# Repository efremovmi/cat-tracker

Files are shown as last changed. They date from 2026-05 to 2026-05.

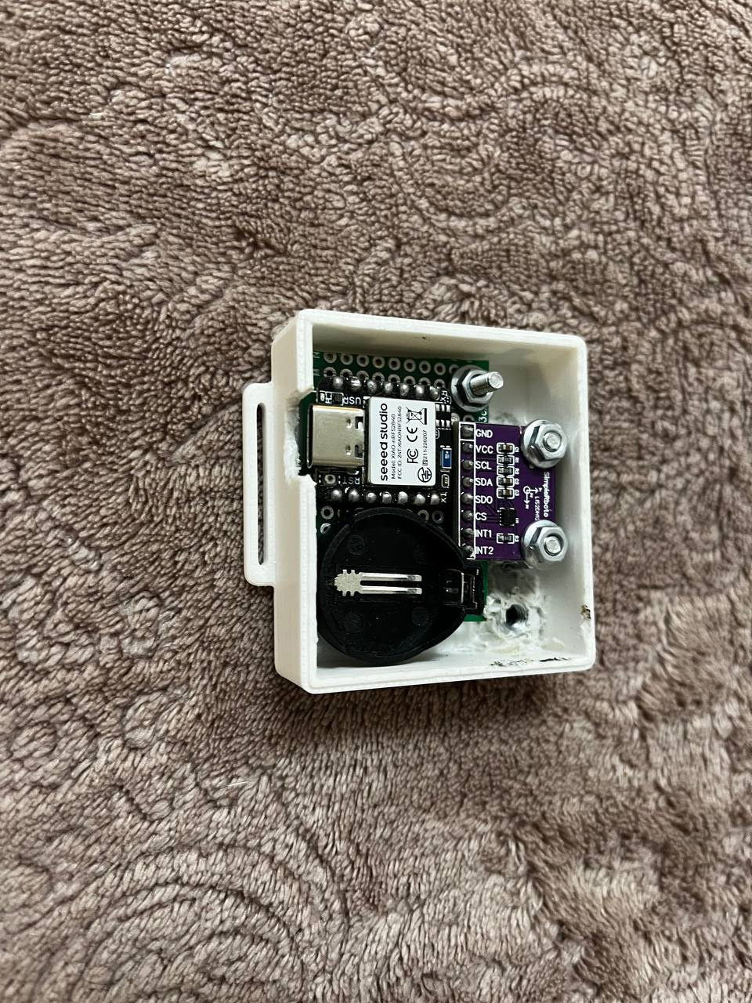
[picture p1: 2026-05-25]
images/6.jpg

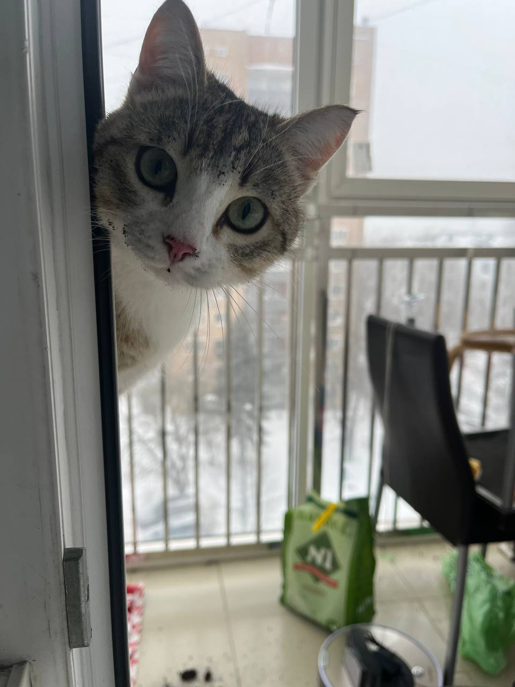
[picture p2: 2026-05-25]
images/1.jpg

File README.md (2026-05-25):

# Cat Activity Tracker (XIAO nRF52840 sence + LIS2DH12)

A cat activity tracker project based on XIAO and the LIS2DH12 accelerometer.
The firmware tracks activity, steps (estimated), distance, jumps, stores hourly statistics, and sends data over BLE.

The project is inspired by nihilism and follows several goals:
- Minimalism
- High autonomy
- Cat safety
- Avoiding an excessive number of unnecessary features
- Enjoying the process
- Helping study the cat's health

## What the system does

- Runs in two sensor modes:
  - `WAKE`: low power, waiting for motion
  - `ACTIVE`: reading samples and motion analysis
- Builds movement segments and filters noise.
- Estimates:
  - `steps` (via stride length)
  - `meters` (via segment duration and speed estimation)
  - `activePoints`
  - `jumps`
- Saves state to Flash (`LittleFS`) and keeps hourly buckets.
- Returns stats via BLE command `GET_STATS`.

## Runtime logic (process)

1. **Device startup**
- Initializes LED, battery ADC, filesystem, accelerometer, and BLE.
- Loads saved state or starts with default parameters.

2. **WAKE mode**
- LIS2DH12 runs at lower frequency and generates `INT1` on activity.
- On IRQ trigger, the device switches to `ACTIVE`.

3. **ACTIVE mode**
- Reads acceleration samples.
- Computes dynamic component (`dyn`) relative to filtered gravity.
- Confirms movement segment start (`pending start` -> `movement ongoing`).
- Counts jumps using `zDyn` with hysteresis and cooldown.
- Finishes segment on silence (`MOTION_END_GAP_MS`) or by `MAX_MOVEMENT_SEGMENT_MS`.

4. **Segment metrics calculation**
- Applies segment quality filters (minimum duration / motion density).
- Estimates speed from average `avgDyn`.
- Calculates meters and steps.
- Writes data to current hourly bucket and total counters.

5. **Background tasks**
- Periodic battery measurement via divider + MOSFET switch.
- Periodic state save to Flash.
- BLE command handling (`TIME_SYNC`, `GET_STATS`, `RESET_STATS`, `DISCONNECT`, `DEBUG_CHANGE`).

## Wiring (single SVG diagram)

Component wiring diagram (SVG)
Wiring diagram

The diagram is made as one sheet: controller, accelerometer, battery, divider, and MOSFET switch node.

## Components table (BOM)

| Component | Qty | Note |
|---|---:|---|
| Seeed XIAO (3.3V, BLE-compatible) | 1 | Main controller |
| LIS2DH12 breakout/module | 1 | Accelerometer, I2C, INT1 |
| CR2032 battery | 1 | Power |
| CR2032 holder | 1 | Power |
| IRLML6344 (N-MOSFET) | 1 | Switch for battery measurement node |
| 1M resistor (R1) | 1 | Divider top resistor |
| 1M resistor (R2) | 1 | Divider bottom resistor |
| 100k resistor | 1 | Series resistor to Gate |
| 1M resistor | 1 | Gate pull-down to GND |
| Wires/assembly | 1 set | Connections |

## Firmware file

- Main firmware: `./cat-tracker.ino`
- BLE desktop client:
- Files with 3 models: `./3d models`
- Project photos: `./images`

## Notes

- Current firmware coefficients are tuned for a cat (not a human).
- The most honest metric is activity.
- For correct hourly statistics after BLE connection, send `TIME_SYNC:<unix_ts>`.

## Plans

- Collect statistics and build metrics
- Measure differences when the cat is played with vs. not given attention

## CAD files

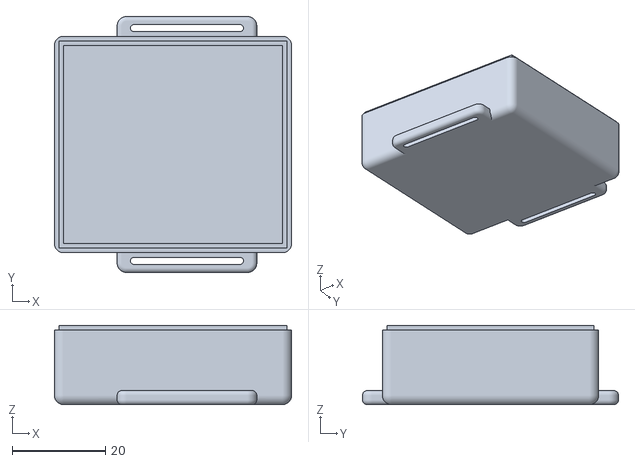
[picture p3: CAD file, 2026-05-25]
3d models/box.stl
51.0 x 55.0 x 17.0

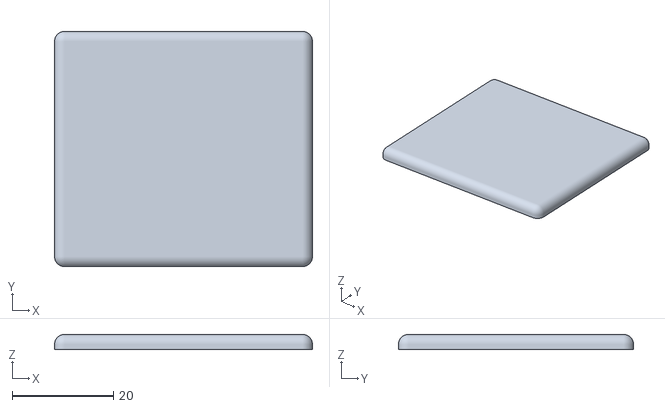
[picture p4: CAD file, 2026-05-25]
3d models/top.stl
51.0 x 46.5 x 3.00

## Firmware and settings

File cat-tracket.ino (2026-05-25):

#include <ArduinoBLE.h>
#include <Wire.h>

#include "mbed.h"
#include "FlashIAPBlockDevice.h"
#include "LittleFileSystem.h"

#include <stdio.h>
#include <stdarg.h>
#include <string.h>
#include <math.h>

using namespace mbed;

// ===================== Settings =====================

// ----- Debug -----
bool debugLogEnabled = true;

// ----- LED indication -----
static const bool HAS_RGB_LED = true;
static const uint32_t BLE_WAIT_BLINK_INTERVAL_MS = 10UL * 1000UL;
static const uint32_t LED_BLINK_ON_MS = 120UL;
static const uint32_t LED_BLINK_OFF_MS = 120UL;
static const uint8_t  DISCONNECT_RED_BLINKS = 5;

// ----- BLE -----
static const char* DEVICE_NAME  = "PET_TRACKER";
static const char* SERVICE_UUID = "19B10000-E8F2-537E-4F6C-D104768A1214";
static const char* RX_UUID      = "19B10001-E8F2-537E-4F6C-D104768A1214";
static const char* TX_UUID      = "19B10002-E8F2-537E-4F6C-D104768A1214";

static const uint32_t BLE_ADVERTISE_WINDOW_MS = 30UL * 1000UL;
static const uint16_t BLE_ADV_INTERVAL_UNITS  = 3200;

// ----- Storage -----
static const uint32_t SAVE_INTERVAL_MS = 60UL * 60UL * 1000UL;
static const uint32_t BATTERY_MEASURE_INTERVAL_MS = 60UL * 60UL * 1000UL;
static const size_t   MAX_HOURLY_BUCKETS = 48;
static const uint32_t PERSIST_MAGIC = 0x50535450;
static const uint32_t PERSIST_VERSION = 20;

static const uint32_t FLASH_FS_BASE = 0x80000;
static const uint32_t FLASH_FS_SIZE = 64 * 1024;
static const char* STATS_FILE_PATH = "/littlefs/pet_steps.bin";

// ----- Battery measurement -----
static const int BATTERY_ADC_PIN     = A0;
static const int BATTERY_MEAS_EN_PIN = D1;

static const float BAT_R1_OHMS = 1000000.0f;
static const float BAT_R2_OHMS = 1000000.0f;

static const int   ADC_MAX_COUNTS      = 4095;
static const float ADC_REFERENCE_VOLTS = 3.0f;

static const float CR2032_FULL_V  = 3.3f;
static const float CR2032_EMPTY_V = 2.0f;

// ----- LIS2DH12 -----
static const uint8_t LIS_ADDR     = 0x18;
static const int     LIS_INT1_PIN = D2;

// ----- Activity score -----
static const float SEG_MOTION_PER_ACTIVE_POINT = 100.0f;

// ----- Human model -----
static const float DEFAULT_STRIDE_METERS = 0.26f;

// ----- Speed estimation from motion intensity -----
static const float DEFAULT_MIN_SPEED_MPS = 0.35f;
static const float DEFAULT_MAX_SPEED_MPS = 1.80f;
static const float DEFAULT_DYN_SPEED_MIN = 18.0f;
static const float DEFAULT_DYN_SPEED_MAX = 95.0f;

// ----- Power / sensor state machine -----
static const uint32_t ACTIVE_WINDOW_MS = 1500;
static const uint32_t QUIET_RETURN_MS  = 5000; //  когда идти спать

// ----- Motion detection tuning -----
static const uint8_t ACTIVE_ODR_25HZ_CTRL1 = 0x3F;
static const uint8_t WAKE_ODR_10HZ_CTRL1   = 0x2F;

static const int32_t GRAV_LP_SHIFT = 4; // Отвечает за то, как быстро оценка гравитации подстраивается.
static const int32_t BASE_LP_SHIFT = 7; // Как быстро подстраивается “база шума”.
static const int32_t MOTION_MIN_RAW = 12; // абсолютно нижний порог
static const int32_t MOTION_MARGIN  = 5; // насколько порог выше фонового base
static const int32_t STRONG_MOTION_EXTRA = 4; // Продление active-окна.
static const int32_t JUMP_Z_DYN_THRESHOLD = 52; // порог прыжка по Z
static const int32_t JUMP_Z_DYN_HYSTERESIS = 8; // защита от повторного срабатывания на пике
static const uint32_t JUMP_COUNT_COOLDOWN_MS = 450; // минимальный интервал между засчитанными прыжками

// Если нет motion-образцов дольше этого интервала, считаем сегмент движения завершённым
static const uint32_t MOTION_END_GAP_MS = 2500;

// Минимальная длительность сегмента
static const uint32_t MIN_MOVEMENT_SEGMENT_MS = 1000; // 1 секунда
// Максимальная длительность сегмента
static const uint32_t MAX_MOVEMENT_SEGMENT_MS = 60UL * 1000UL; // 1 минута

// ===== Защита от шума / ударов =====
// Нужно столько подряд motion-сэмплов, чтобы начать сегмент
static const uint8_t MOTION_START_CONFIRM_COUNT = 2;

// Если между motion-сэмплами слишком большая пауза — сбрасываем кандидат на старт
static const uint32_t MOTION_START_CONFIRM_GAP_MS = 800;

// Минимум "настоящих" motion-сэмплов в сегменте
static const uint32_t MIN_SEGMENT_MOTION_SAMPLES = 4;

// Минимальная доля motion-сэмплов среди всех сэмплов сегмента
static const float MIN_SEGMENT_MOTION_RATIO = 0.10f;

// Минимальный средний dyn сегмента, чтобы отсечь слабый шум
static const float MIN_SEGMENT_AVG_DYN = 12.0f;

// ===================== REGISTERS LIS2DH12 =====================

static const uint8_t REG_WHO_AM_I       = 0x0F;
static const uint8_t REG_CTRL_REG1      = 0x20;
static const uint8_t REG_CTRL_REG2      = 0x21;
static const uint8_t REG_CTRL_REG3      = 0x22;
static const uint8_t REG_CTRL_REG4      = 0x23;
static const uint8_t REG_CTRL_REG5      = 0x24;
static const uint8_t REG_CTRL_REG6      = 0x25;
static const uint8_t REG_REFERENCE      = 0x26;
static const uint8_t REG_STATUS_REG     = 0x27;
static const uint8_t REG_OUT_X_L        = 0x28;
static const uint8_t REG_INT1_CFG       = 0x30;
static const uint8_t REG_INT1_SRC       = 0x31;
static const uint8_t REG_INT1_THS       = 0x32;
static const uint8_t REG_INT1_DURATION  = 0x33;

// ===================== BLE =====================

BLEService petService(SERVICE_UUID);
BLEStringCharacteristic rxChar(RX_UUID, BLEWrite, 120);
BLEStringCharacteristic txChar(TX_UUID, BLERead | BLENotify, 1024);

// ===================== FILESYSTEM =====================

FlashIAPBlockDevice flashBD(FLASH_FS_BASE, FLASH_FS_SIZE);
mbed::LittleFileSystem fs("littlefs");
bool fsReady = false;

// ===================== TYPES =====================

struct HourBucket {
  uint32_t hourKey;
  uint32_t steps;
  float meters;
  float activePoints;
  uint32_t jumps;
};

struct PersistedState {
  uint32_t magic;
  uint32_t version;
  uint32_t timeSynced;
  int64_t  unixTimeBase;
  uint32_t millisAtSync;

  uint8_t debugLogEnabled;

  float strideMeters;
  float minSpeedMps;
  float maxSpeedMps;
  float dynSpeedMin;
  float dynSpeedMax;

  uint32_t totalSteps;
  float totalMeters;
  float totalActivePoints;
  uint32_t totalJumps;

  float batteryVoltage;
  int32_t batteryPercent;
  uint32_t lastBatteryMeasureMillis;

  uint32_t bucketCount;
  HourBucket buckets[MAX_HOURLY_BUCKETS];
};

struct Sample3 {
  int16_t x;
  int16_t y;
  int16_t z;
};

enum SensorMode {
  SENSOR_WAKE = 0,
  SENSOR_ACTIVE = 1
};

struct MotionDetectorState {
  bool initialized = false;

  int32_t gx = 0;
  int32_t gy = 0;
  int32_t gz = 0;

  int32_t base = 0;

  bool movementOngoing = false;
  uint32_t movementStartMs = 0;
  uint32_t lastMotionMs = 0;

  uint64_t segmentDynSum = 0;
  uint32_t segmentSampleCount = 0;
  uint32_t segmentMotionSampleCount = 0;
  uint32_t segmentMotionJump = 0;
  int32_t segmentDynPeak = 0;
  int32_t lastDynZ = 0;
  bool jumpPeakLatched = false;
  uint32_t lastJumpCountMs = 0;

  uint8_t pendingStartCount = 0;
  uint32_t pendingStartFirstMs = 0;
  uint32_t pendingStartLastMs = 0;
};

// ===================== GLOBALS =====================

PersistedState state;
MotionDetectorState motionDet;

BLEDevice currentCentral;

bool bleStarted = false;
bool bleAdvertising = false;
bool clientConnected = false;
bool disconnectRequested = false;
bool dirty = false;

volatile bool lisIntFlag = false;
volatile uint32_t lisIntCount = 0;
volatile bool saveTimerFlag = false;

uint32_t bootMillis = 0;
uint32_t activeUntilMs = 0;
uint32_t lastStrongMotionMs = 0;

SensorMode sensorMode = SENSOR_WAKE;

LowPowerTimeout saveTimer;

uint32_t lastBleWaitBlinkMillis = 0;
bool pendingDisconnectRedBlinkSequence = false;

// ===================== LOG =====================

void logLine(const String& s) {
  if (debugLogEnabled) Serial.println(s);
}

// ===================== SPEED =====================

float clampFloat(float v, float lo, float hi) {
  if (v < lo) return lo;
  if (v > hi) return hi;
  return v;
}

float estimateSpeedFromAvgDyn(float avgDyn) {
  float dynMin = state.dynSpeedMin;
  float dynMax = state.dynSpeedMax;

  if (dynMax <= dynMin) {
    return state.minSpeedMps;
  }

  float t = (avgDyn - dynMin) / (dynMax - dynMin);
  t = clampFloat(t, 0.0f, 1.0f);

  float speed = state.minSpeedMps + t * (state.maxSpeedMps - state.minSpeedMps);
  return speed;
}

// ===================== LED =====================

void ledOffAll() {
  if (!HAS_RGB_LED) return;

  pinMode(LED_RED, OUTPUT);
  pinMode(LED_GREEN, OUTPUT);
  pinMode(LED_BLUE, OUTPUT);

  digitalWrite(LED_RED, HIGH);
  digitalWrite(LED_GREEN, HIGH);
  digitalWrite(LED_BLUE, HIGH);
}

void blinkGreenOnce() {
  if (!HAS_RGB_LED) return;

  ledOffAll();
  digitalWrite(LED_GREEN, LOW);
  delay(LED_BLINK_ON_MS);
  digitalWrite(LED_GREEN, HIGH);
}

void blinkRedSequence(uint8_t times) {
  if (!HAS_RGB_LED) return;

  ledOffAll();
  for (uint8_t i = 0; i < times; i++) {
    digitalWrite(LED_RED, LOW);
    delay(LED_BLINK_ON_MS);
    digitalWrite(LED_RED, HIGH);
    if (i + 1 < times) {
      delay(LED_BLINK_OFF_MS);
    }
  }
}

// ===================== TIME/STATS =====================

uint32_t getBootHourKey() {
  return (uint32_t)(millis() / 3600000UL);
}

uint32_t getCurrentHourKey() {
  if (state.timeSynced) {
    int64_t nowUnix = state.unixTimeBase + ((int64_t)(millis() - state.millisAtSync) / 1000LL);
    if (nowUnix < 0) nowUnix = 0;
    return (uint32_t)(nowUnix / 3600LL);
  }
  return getBootHourKey();
}

String formatHourLabel(uint32_t hourKey) {
  return state.timeSynced ? ("UNIX_HOUR_" + String(hourKey))
                          : ("BOOT_HOUR_" + String(hourKey));
}

void clearStatsInRam() {
  memset(state.buckets, 0, sizeof(state.buckets));
  state.bucketCount = 0;
  state.totalSteps = 0;
  state.totalMeters = 0.0f;
  state.totalActivePoints = 0.0f;
  state.totalJumps = 0;
  dirty = true;
  logLine("[STATS] Cleared");
}

void addMovementToCurrentHour(float metersToAdd, float activePointsToAdd, uint32_t jumpsToAdd) {
  if (metersToAdd <= 0.0f && activePointsToAdd <= 0.0f && jumpsToAdd == 0) return;

  uint32_t stepsToAdd = (uint32_t)roundf(metersToAdd / state.strideMeters);
  const uint32_t hourKey = getCurrentHourKey();

  state.totalMeters += metersToAdd;
  state.totalSteps += stepsToAdd;
  state.totalActivePoints += activePointsToAdd;
  state.totalJumps += jumpsToAdd;

  for (uint32_t i = 0; i < state.bucketCount; i++) {
    if (state.buckets[i].hourKey == hourKey) {
      state.buckets[i].meters += metersToAdd;
      state.buckets[i].steps += stepsToAdd;
      state.buckets[i].activePoints += activePointsToAdd;
      state.buckets[i].jumps += jumpsToAdd;
      dirty = true;

      logLine("[STATS] +" + String(metersToAdd, 2) + " m, +" +
              String(stepsToAdd) + " steps, +" +
              String(activePointsToAdd, 2) + " active points, +" +
              String(jumpsToAdd) + " jumps in " + formatHourLabel(hourKey));
      return;
    }
  }

  if (state.bucketCount < MAX_HOURLY_BUCKETS) {
    state.buckets[state.bucketCount].hourKey = hourKey;
    state.buckets[state.bucketCount].steps = stepsToAdd;
    state.buckets[state.bucketCount].meters = metersToAdd;
    state.buckets[state.bucketCount].activePoints = activePointsToAdd;
    state.buckets[state.bucketCount].jumps = jumpsToAdd;
    state.bucketCount++;
  } else {
    memmove(&state.buckets[0], &state.buckets[1], sizeof(HourBucket) * (MAX_HOURLY_BUCKETS - 1));
    state.buckets[MAX_HOURLY_BUCKETS - 1].hourKey = hourKey;
    state.buckets[MAX_HOURLY_BUCKETS - 1].steps = stepsToAdd;
    state.buckets[MAX_HOURLY_BUCKETS - 1].meters = metersToAdd;
    state.buckets[MAX_HOURLY_BUCKETS - 1].activePoints = activePointsToAdd;
    state.buckets[MAX_HOURLY_BUCKETS - 1].jumps = jumpsToAdd;
  }

  dirty = true;
  logLine("[STATS] New bucket " + formatHourLabel(hourKey) +
          ", meters=" + String(metersToAdd, 2) +
          ", steps=" + String(stepsToAdd) +
          ", activePoints=" + String(activePointsToAdd, 2) +
          ", jumps=" + String(jumpsToAdd));
}

String buildStatsPayload() {
  static const size_t MAX_STATS_PAYLOAD_LEN = 900;
  char out[MAX_STATS_PAYLOAD_LEN];
  out[0] = '\0';
  size_t used = 0;

  auto appendRaw = [&](const char* s) -> bool {
    size_t n = strlen(s);
    if (used + n >= MAX_STATS_PAYLOAD_LEN) return false;
    memcpy(out + used, s, n);
    used += n;
    out[used] = '\0';
    return true;
  };

  auto appendf = [&](const char* fmt, ...) -> bool {
    if (used >= MAX_STATS_PAYLOAD_LEN - 1) return false;
    va_list args;
    va_start(args, fmt);
    int written = vsnprintf(out + used, MAX_STATS_PAYLOAD_LEN - used, fmt, args);
    va_end(args);
    if (written < 0) return false;
    if ((size_t)written >= (MAX_STATS_PAYLOAD_LEN - used)) {
      used = MAX_STATS_PAYLOAD_LEN - 1;
      out[used] = '\0';
      return false;
    }
    used += (size_t)written;
    return true;
  };

  updateBatteryInRam();

  bool ok = true;
  ok &= appendRaw("OK:STATS\n");
  ok &= appendf("TIME_MODE=%s\n", state.timeSynced ? "SYNCED" : "BOOT_RELATIVE");
  ok &= appendf("TOTAL_STEPS=%lu\n", (unsigned long)state.totalSteps);
  ok &= appendf("TOTAL_METERS=%.2f\n", (double)state.totalMeters);
  ok &= appendf("TOTAL_ACTIVE_POINTS=%.2f\n", (double)state.totalActivePoints);
  ok &= appendf("TOTAL_JUMPS=%lu\n", (unsigned long)state.totalJumps);
  ok &= appendf("SEGMENT_JUMPS=%lu\n", (unsigned long)motionDet.segmentMotionJump);
  ok &= appendf("BATTERY_V=%.3f\n", (double)state.batteryVoltage);
  ok &= appendf("BATTERY_PERCENT=%ld\n", (long)state.batteryPercent);
  ok &= appendf("SENSOR_MODE=%d\n", (int)sensorMode);
  ok &= appendf("BUCKETS=%lu\n", (unsigned long)state.bucketCount);

  for (uint32_t i = 0; i < state.bucketCount; i++) {
    if (!ok) break;
    String hourLabel = formatHourLabel(state.buckets[i].hourKey);
    ok &= appendf("%s:STEPS=%lu,METERS=%.2f,ACTIVE_POINTS=%.2f,JUMPS=%lu\n",
                  hourLabel.c_str(),
                  (unsigned long)state.buckets[i].steps,
                  (double)state.buckets[i].meters,
                  (double)state.buckets[i].activePoints,
                  (unsigned long)state.buckets[i].jumps);
  }

  if (!ok) {
    if (used + strlen("TRUNCATED=1\n") < MAX_STATS_PAYLOAD_LEN) {
      appendRaw("TRUNCATED=1\n");
    } else if (MAX_STATS_PAYLOAD_LEN >= 2) {
      out[MAX_STATS_PAYLOAD_LEN - 2] = '\n';
      out[MAX_STATS_PAYLOAD_LEN - 1] = '\0';
    }
  }

  return String(out);
}

// ===================== FLASH =====================

bool initFilesystem() {
  int err = fs.mount(&flashBD);
  if (err) {
    err = fs.reformat(&flashBD);
    if (err) {
      logLine("[FS] Reformat failed, code=" + String(err));
      return false;
    }
    err = fs.mount(&flashBD);
    if (err) {
      logLine("[FS] Mount after format failed, code=" + String(err));
      return false;
    }
  }
  return true;
}

bool saveStateToFlash() {
  if (!fsReady) {
    logLine("[FS] save skipped: FS not ready");
    return false;
  }

  FILE* f = fopen(STATS_FILE_PATH, "wb");
  if (!f) {
    logLine("[FS] Failed to open file for write");
    return false;
  }

  size_t written = fwrite(&state, 1, sizeof(state), f);
  fclose(f);

  if (written != sizeof(state)) {
    logLine("[FS] Incomplete write");
    return false;
  }

  dirty = false;
  return true;
}

bool loadStateFromFlash() {
  if (!fsReady) return false;

  FILE* f = fopen(STATS_FILE_PATH, "rb");
  if (!f) {
    logLine("[FS] No saved state");
    return false;
  }

  PersistedState loaded;
  size_t rd = fread(&loaded, 1, sizeof(loaded), f);
  fclose(f);

  if (rd != sizeof(loaded)) {
    logLine("[FS] Saved state size mismatch");
    return false;
  }

  if (loaded.magic != PERSIST_MAGIC || loaded.version != PERSIST_VERSION) {
    logLine("[FS] Version mismatch, start fresh");
    return false;
  }

  state = loaded;
  if (state.bucketCount > MAX_HOURLY_BUCKETS) {
    state.bucketCount = MAX_HOURLY_BUCKETS;
  }

  debugLogEnabled = (state.debugLogEnabled != 0);

  return true;
}

void initFreshState() {
  memset(&state, 0, sizeof(state));
  state.magic = PERSIST_MAGIC;
  state.version = PERSIST_VERSION;
  state.debugLogEnabled = 1;
  state.strideMeters = DEFAULT_STRIDE_METERS;
  state.minSpeedMps = DEFAULT_MIN_SPEED_MPS;
  state.maxSpeedMps = DEFAULT_MAX_SPEED_MPS;
  state.dynSpeedMin = DEFAULT_DYN_SPEED_MIN;
  state.dynSpeedMax = DEFAULT_DYN_SPEED_MAX;
  state.totalActivePoints = 0.0f;
  state.totalJumps = 0;
  state.batteryVoltage = 0.0f;
  state.batteryPercent = 0;
  state.lastBatteryMeasureMillis = 0;

  debugLogEnabled = true;
  dirty = false;
}

// ===================== BATTERY =====================

int batteryPercentFromVoltage(float v) {
  if (v >= CR2032_FULL_V) return 100;
  if (v <= CR2032_EMPTY_V) return 0;

  float p = (v - CR2032_EMPTY_V) / (CR2032_FULL_V - CR2032_EMPTY_V);
  int percent = (int)(p * 100.0f + 0.5f);

  if (percent < 0) percent = 0;
  if (percent > 100) percent = 100;
  return percent;
}

float readBatteryVoltageOnce() {
  digitalWrite(BATTERY_MEAS_EN_PIN, HIGH);

  analogRead(BATTERY_ADC_PIN);
  analogRead(BATTERY_ADC_PIN);

  uint32_t sum = 0;
  const int samples = 8;
  for (int i = 0; i < samples; i++) {
    sum += analogRead(BATTERY_ADC_PIN);
  }

  digitalWrite(BATTERY_MEAS_EN_PIN, LOW);

  float raw = (float)sum / (float)samples;
  float vAdc = (raw / (float)ADC_MAX_COUNTS) * ADC_REFERENCE_VOLTS;
  float vBat = vAdc * ((BAT_R1_OHMS + BAT_R2_OHMS) / BAT_R2_OHMS);

  return vBat;
}

void updateBatteryInRam() {
  float vBat = readBatteryVoltageOnce();
  int pct = batteryPercentFromVoltage(vBat);

  state.batteryVoltage = vBat;
  state.batteryPercent = pct;
  state.lastBatteryMeasureMillis = millis();
  dirty = true;

}

void periodicBatteryMeasureIfNeeded() {
  uint32_t now = millis();

  if (state.lastBatteryMeasureMillis == 0 ||
      (now - state.lastBatteryMeasureMillis) >= BATTERY_MEASURE_INTERVAL_MS) {
    updateBatteryInRam();
  }
}

// ===================== LIS LOW LEVEL =====================

bool lisWriteReg(uint8_t reg, uint8_t value) {
  Wire.beginTransmission(LIS_ADDR);
  Wire.write(reg);
  Wire.write(value);
  return Wire.endTransmission() == 0;
}

bool lisReadReg(uint8_t reg, uint8_t &value) {
  Wire.beginTransmission(LIS_ADDR);
  Wire.write(reg);
  if (Wire.endTransmission(false) != 0) return false;

  if (Wire.requestFrom((int)LIS_ADDR, 1) != 1) return false;
  value = Wire.read();
  return true;
}

bool lisReadRegs(uint8_t reg, uint8_t* dst, size_t len) {
  Wire.beginTransmission(LIS_ADDR);
  Wire.write(reg | 0x80);
  if (Wire.endTransmission(false) != 0) return false;

  size_t got = Wire.requestFrom((int)LIS_ADDR, (int)len);
  if (got != len) return false;

  for (size_t i = 0; i < len; i++) dst[i] = Wire.read();
  return true;
}

// ===================== TIMER / ISR =====================

void onSaveTimerISR() {
  saveTimerFlag = true;
}

void armSaveTimer() {
  saveTimer.detach();
  saveTimer.attach(&onSaveTimerISR, std::chrono::milliseconds(SAVE_INTERVAL_MS));
}

void lisIntISR() {
  lisIntFlag = true;
  lisIntCount++;
}

// ===================== MOTION DETECTOR =====================

void resetMotionDetector() {
  motionDet = MotionDetectorState{};
}

int32_t dynFromSampleAndUpdateFilters(const Sample3& s) {
  const int32_t x = s.x;
  const int32_t y = s.y;
  const int32_t z = s.z;

  if (!motionDet.initialized) {
    motionDet.gx = x;
    motionDet.gy = y;
    motionDet.gz = z;
    motionDet.initialized = true;
  }

  motionDet.gx += (x - motionDet.gx) >> GRAV_LP_SHIFT;
  motionDet.gy += (y - motionDet.gy) >> GRAV_LP_SHIFT;
  motionDet.gz += (z - motionDet.gz) >> GRAV_LP_SHIFT;

  const int32_t dx = x - motionDet.gx;
  const int32_t dy = y - motionDet.gy;
  const int32_t dz = z - motionDet.gz;

  const int32_t adx = abs(dx);
  const int32_t ady = abs(dy);
  const int32_t adz = abs(dz);
  motionDet.lastDynZ = adz;

  const int32_t dyn = max(adx, max(ady, adz));

  motionDet.base += (dyn - motionDet.base) >> BASE_LP_SHIFT;
  return dyn;
}

int32_t getMotionThreshold() {
  return (motionDet.base + MOTION_MARGIN > MOTION_MIN_RAW)
           ? (motionDet.base + MOTION_MARGIN)
           : MOTION_MIN_RAW;
}

void updateSegmentJumpFromZDyn() {
  if (motionDet.lastDynZ >= JUMP_Z_DYN_THRESHOLD) {
    if (!motionDet.jumpPeakLatched) {
      uint32_t now = millis();
      if (motionDet.lastJumpCountMs == 0 ||
          (uint32_t)(now - motionDet.lastJumpCountMs) >= JUMP_COUNT_COOLDOWN_MS) {
        motionDet.segmentMotionJump++;
        motionDet.lastJumpCountMs = now;
      }
      motionDet.jumpPeakLatched = true;
    }
    return;
  }

  if (motionDet.lastDynZ <= (JUMP_Z_DYN_THRESHOLD - JUMP_Z_DYN_HYSTERESIS)) {
    motionDet.jumpPeakLatched = false;
  }
}

void restartMovementSegmentNow(uint32_t now, int32_t dyn) {
  motionDet.movementOngoing = true;
  motionDet.movementStartMs = now;
  motionDet.lastMotionMs = now;

  motionDet.segmentDynSum = (uint64_t)dyn;
  motionDet.segmentSampleCount = 1;
  motionDet.segmentMotionSampleCount = 1;
  motionDet.segmentMotionJump = 0;
  motionDet.segmentDynPeak = dyn;
  motionDet.jumpPeakLatched = false;
  updateSegmentJumpFromZDyn();

  motionDet.pendingStartCount = 0;
  motionDet.pendingStartFirstMs = 0;
  motionDet.pendingStartLastMs = 0;

}
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
void loop() {
  if (bleStarted) {
    serviceBle();
  }

  if (bleStarted && !clientConnected && bleAdvertising) {
    if (millis() - bootMillis >= BLE_ADVERTISE_WINDOW_MS) {
      stopBleCompletely();
      pendingDisconnectRedBlinkSequence = true;
    }
  }

  processBleWaitLed();
  processDisconnectLedSequence();

  processLisInterrupts();
  maybeReturnToWakeMode();

  periodicBatteryMeasureIfNeeded();
  processSaveTimer();

  sleep();
}
